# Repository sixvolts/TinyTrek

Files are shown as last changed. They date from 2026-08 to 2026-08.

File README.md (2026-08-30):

# ttos-ctf — TinyTrekOS

A small autonomous-ish car built to be hacked, and the Yocto Linux distribution
that runs it. Eight identical vehicles, each a genuine automotive network in
miniature: two CAN buses, three microcontroller nodes, a battery manager that
watches the drivetrain, and an operator panel served over the car's own WiFi that
starts out locked and opens as you solve it.

It was built for an authorized, educational capture-the-flag event. The three
challenges are the real thing rather than a simulation of one — a UDS diagnostic
server on CAN FD, an AUTOSAR-style end-to-end CRC protecting the drive bus, and
an in-kernel CAN gateway between the two — which is the point. What a team learns
breaking this car transfers to a real one.

> **Authorized use only.** Everything here targets hardware you own and a network
> with nothing else on it. Applying any of it to a vehicle you do not own, or to
> one on a public road, is neither the intent nor defensible.

> **Spoilers.** This repository is the complete build *including the answers*.
> [`WALKTHROUGH.md`](WALKTHROUGH.md) is a full solution guide, [`ARCHITECTURE.md`](ARCHITECTURE.md)
> §6 explains every mechanism, and the live flag codes appear in both. If you are
> planning to *play* one of these cars, read [`BOARD.md`](BOARD.md) and stop there.

---

## Hardware

| Part | Detail |
|---|---|
| Compute | Raspberry Pi 4, 2 GB |
| CAN | Waveshare 2-CH CAN FD HAT Rev2.1, "Mode A" (two independent SPI buses), MCP2518FD ×2 |
| Motor nodes ×2 | Adafruit QT Py SAMD21 + MCP2515, stepper drivers |
| BMS node | Adafruit Feather RP2040 CAN (built-in MCP2518FD), 12 V relay, pack-voltage sense |
| Battery | 3S pack, 8.4 V–12.3 V |

Two buses: **`can0` is DIAG** (CAN FD, 500 kbit / 1 Mbit, terminating at the
contestant's diagnostic tap) and **`can1` is DRIVE** (classic CAN 2.0, 500 kbit,
both motors plus the BMS). That naming is inverted relative to the original design
notes and it matters — see [SYSTEM-OVERVIEW.md §2](SYSTEM-OVERVIEW.md) before you
touch anything bus-related. The Pi reaches the nodes over CAN and nothing else.

## Documentation

Read in roughly this order. [`ARCHITECTURE.md`](ARCHITECTURE.md) is the source of
truth — where an older document disagrees with it, it wins.

| Document | What it covers |
|---|---|
| [ARCHITECTURE.md](ARCHITECTURE.md) | **Source of truth.** Physical layout, full CAN message map, where every secret lives, the gateway, all three challenges as built, detection and judging, panel tiers |
| [SYSTEM-OVERVIEW.md](SYSTEM-OVERVIEW.md) | The platform beneath the challenges: hardware, buses, networking, dashboard, boot and provisioning, security posture |
| [BOARD.md](BOARD.md) | Contestant-facing board copy. Safe to print or post — reveals no solutions |
| [WALKTHROUGH.md](WALKTHROUGH.md) | **Answer key.** Solving all three by hand on a real car, with the reasoning at each step |
| [THIRD-PARTY.md](THIRD-PARTY.md) | Vendored components and their licenses |
| [firmware/README.md](firmware/README.md) | The three CAN node sketches |
| [firmware/FLASHING.md](firmware/FLASHING.md) | Flashing nodes, per-car and bench modes |
| [provisioning/README.md](provisioning/README.md) | Fleet data model — how eight cars get eight identities from one image |
| [bench/README.md](bench/README.md) | The development bench rig as actually wired, and the test suite |

## Layout

```
ttos-ctf/
  meta-tt-ctf/            the Yocto layer — distro, machine, image, and every app
    recipes-apps/         ttos-dashboard (Go): panel, UDS server, CTF logic
    recipes-provision/    first-boot per-car identity
    recipes-support/      ttos-selftest, ttos-bringup, operator tooling
    recipes-core/         image definitions, systemd units, network config
    recipes-kernel/       CAN kconfig, mcp251xfd
  hardware/               build it yourself — BOM, board fab files, 3D models, schematics, build guide
  firmware/               Arduino sketches for the two motor nodes and the BMS
  bench/                  bench rig control, vehicle emulator, test suite
  tools/                  operator tooling
    ttos-ctf-tool.py      drives a car over CAN — the whole challenge chain
    linux-kit/            self-contained kit for an operator laptop
  provisioning/           fleet generation (data itself is gitignored — see below)
  kas/                    build configs
  docker/                 pinned build container
  build.sh                container build wrapper
  apps/dashboard          → symlink into meta-tt-ctf, for convenient editing
```

## Build

Needs Docker and a fast scratch directory. Upstream Yocto layers (`poky`,
`meta-openembedded`, `meta-raspberrypi`) are cloned into the repo root by `kas`
at build time and are deliberately not committed — `kas/ttos-ctf.yml` is the
source of truth for their revisions.

```bash
tmux new -s ttos                # a first build is long; sessions drop
./build.sh --build              # build the container, then the production image
./build.sh kas/ttos-ctf-dev.yml # bench/dev image instead
```

Build directories (`TMPDIR`, `SSTATE_DIR`, `DL_DIR`) live under `$TTOS_YOCTO_DIR`
(default `$HOME/yocto`), **outside** the source tree, so `rm -rf build/` does not
destroy sstate or downloads. The image lands in
`$TTOS_YOCTO_DIR/tmp-glibc/deploy/images/ttos-ctf-hw/`; flash it with
`bmaptool copy`.

## Bringing up a car

One image serves the whole fleet; per-car identity is applied on first boot from
`ttos-provision.conf` on the FAT boot partition — hostname, car id, WiFi
credentials, console password hash, challenge constants. Provisioning is
idempotent, regenerates per-car SSH host keys, then wipes the file off the FAT
partition. A missing or malformed file makes the car fail loudly on the console
rather than boot with defaults.

An **unprovisioned** card boots into factory mode: a known AP, driving enabled,
no challenge gating — which is what `tools/ttos-bringup.sh` uses to verify a
freshly assembled car before it gets an identity.

The panel is at `http://192.168.244.1` once you join the car's AP. **Use Safari
or Firefox** — Chrome's "always use secure connections" upgrades that URL to
HTTPS, which is not served, and the panel looks dead when it is fine.

## Secrets

Per-car provisioning data — WiFi PSKs, console password hashes, CRC data IDs,
challenge codes — is generated into `provisioning/` and is **gitignored**. Only
the generator scripts are tracked; `render-fleet.py` rebuilds every derived
artifact deterministically from `fleet-table.csv`. Back that file up somewhere
off this repository: losing it means reflashing every node in the fleet with new
values.

The flag codes themselves *are* in this repository, in the walkthrough and the
architecture document, because the event they were built for is over.

## License

MIT — see [LICENSE](LICENSE). Vendored third-party components keep their own
licenses, some of them LGPL; see [THIRD-PARTY.md](THIRD-PARTY.md).

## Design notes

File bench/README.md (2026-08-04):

# TTOS CTF bench rig — as built

Companion to `ttos-ctf-bench-rig.md` (the design brief) and `ARCHITECTURE.md`.
This file records what is actually wired and running on `arcana`, and **where the
brief is wrong**. Where the two disagree, this file is the one that was measured.

Built and verified 2026-08-03.

---

## Quick start

```sh
sudo ./bench-up.sh          # bring both buses up, prove the role mapping
./harness-selftest.py       # prove the harness can be trusted  <-- do not skip
./bench-status.sh           # what is the DUT actually running
./push-dashboard.sh         # rebuild + swap the Go binary, ~2 s
./push-config.sh            # sync bus config, gateway policy, selftest, units
```

---

## Topology as wired

| Role | arcana iface | Adapter | Config | Far side |
|---|---|---|---|---|
| DRIVE | `ttdrive` | Pro FD ch.1 (`dev_id 0x1`) | classic 500 k | DUT `candrive` |
| DIAG | `ttdiag` | Pro FD ch.0 (`dev_id 0x0`) | FD 500 k / 1 M | DUT `candiag` |
| DIAG (car) | `ttcardiag` | PCAN-USB FD, `0a:00.3-usb-0:3` | FD 500 k / 1 M | car 02 diagnostic port |

**The vehicle is normally NOT attached.** Car 02 sat on `ttcardiag` during
development; it goes to the event. The DUT stays, so the bench remains useful
remotely — but it is worth being exact about what that does and does not cover.

| Runs against the DUT (emulated nodes) | Needs a real vehicle |
|---|---|
| `harness-selftest`, `test-uds`, `test-gateway` | `soak.py` — C5 and D11 |
| `test-detectors`, `test-challenge`, `test-c3` | anything about real firmware timing |
| `test-panel` (incl. `--reboot`), `test-relay` | physical motion, real drivetrain |
| `bench-status`, `push-*`, `measure-drive` | the 12 V rail actually switching |

The DUT proves the **protocol and the logic**. It cannot prove the **firmware**:
`vehicle-emulator.py` is a Python model of the BMS and motor nodes, and a passing
detector test says the rules are right, not that the RP2040 implements them. That
distinction has already mattered twice — the C2 pair-window bug and the dead 12 V
rail were both found on a real car, and the second was actively masked on the bench
because `emu-ctl rail on` forces the rail that no product path was setting.

`soak.py` refuses to run without a vehicle rather than failing deeper with a socket
error, and says which of the two things is missing.

**The DUT rig is one dual-channel PCAN-USB Pro FD** since 2026-08-04, replacing two
single-channel dongles. That change broke the old port-based pinning outright:
**both channels share one `ID_PATH`**, because they are one USB interface. A rule
keyed on the port matched whichever channel probed first and left the other as
`can1` — the same probe-order race this project already fought on the Pi.
`peak_usb/can_channel_id` is no help either; it reads `80FF0000` on both. The
discriminator is `ATTR{dev_id}`, the channel index.

The DUT names its own interfaces by role too, from `10-ttos-can.rules` in the
image — `candrive` is the HAT's CAN0 terminal (`spi0.0`), `candiag` is CAN1
(`spi1.0`). Both sides therefore read as roles end to end, and neither depends on
kernel probe order.

DUT: `192.168.4.133`, user `ttos`, unprovisioned (factory mode, password `ttos`).
Key auth is installed from `arcana`, so scripts run without a password prompt;
`sudo` on the DUT is fed the factory password on stdin rather than being given a
NOPASSWD drop-in, so the DUT keeps stock privilege config.

Adapters are two **PEAK PCAN-USB FD** — both FD-capable, so the brief's "this
leaves both table loaners free" holds.

---

## Corrections to the brief

### 1. `CAN_RAW_LOOPBACK` on the observer does nothing (§3)

The brief calls this the cleaner of its two fixes for the loopback trap. It does
not work. Measured here:

```
LOOPBACK=0 on the RECEIVER  -> receiver still saw the injected frame
LOOPBACK=0 on the SENDER    -> receiver did not
```

The option governs whether frames **that socket transmits** are echoed to other
local sockets. On a receive-only socket it suppresses the echo of frames it never
sends, i.e. nothing.

Worse, an observer built to the brief still **passes the brief's own self-test**,
because that test only asks whether the injected frame was absent — and a socket
that receives nothing at all answers yes. So the prescribed check certifies the
broken implementation.

`ttoscan.Observer` filters on the receive side instead: the kernel sets
`MSG_DONTROUTE` in `recvmsg` `msg_flags` for any frame that came from a local
socket, and leaves it clear for frames off the wire (measured: `0x4` for injected,
`0x0` for the DUT's heartbeat). This beats both of the brief's options — sender-side
suppression only covers injectors that opt in, so `cansend`, ad-hoc scripts and the
panel all still leak; frame bookkeeping needs every transmitter to report to a
ledger. `MSG_DONTROUTE` is the kernel's own statement of provenance and needs
cooperation from nobody.

`harness-selftest.py` therefore adds **positive controls** (T1, T3) around the
negative check (T2). T2 alone is unfalsifiable.

### 2. Adapters are pinned to role names, not numbers (§1)

A script that says "observe `ttdiag`" cannot be silently backwards, whatever the
cabling is. That paid for itself on 2026-08-03, when the bus roles turned out to be
the reverse of what the config claimed — DRIVE is the car's `can0`, not `can1` —
and correcting the whole rig took two lines and no cable moved.

**And then it bit, because the same commit edited these two lines as well.** The
car-side correction was right; the bench mapping was already right and got
inverted along with it. For a day, every bench observation was on the wrong wire:
the DUT looked silent on DRIVE while transmitting normally. Nothing failed loudly,
because a swapped pair makes negative assertions pass.

The rule that falls out of that: **which arcana USB port is cabled to which DUT
bus is a physical fact, and a role correction at the far end is never also a
correction here.** Verify this file against traffic, not against reasoning about
the other end — which is exactly what `bench-up.sh` does, and it catches this
inversion in 1.5 s. It simply had not been run in between.

### 3. Pin by USB port, not adapter serial (§2)

PCAN-USB FD publishes no USB `iSerial`; there is no serial to match on. The rules
key on `ID_PATH` (physical port). **The role follows the port, not the adapter** —
move a cable and the roles move with it. `bench-up.sh` re-verifies the mapping
against the DUT's 0x100 heartbeat on every run, so a mis-plug aborts instead of
inverting every result.

### 4. `cmd/ctfd` / `ttos-ctfd` do not exist (§5)

There is no separate CTF daemon. The challenge layer lives inside the dashboard:
`cmd/dashboard/ctf.go` and `cmd/dashboard/uds.go`. Building `./cmd/ctfd` fails
loudly (fine); restarting a nonexistent `ttos-ctfd` succeeds *quietly* and leaves
the old code running (not fine). `push-dashboard.sh` targets `ttos-dashboard`.

### 5. `install(1)` is not on the DUT

busybox is built without it. `push-dashboard.sh` uses `cp` + `chmod` + `mv`, which
keeps the atomic-rename property that matters (the running process holds its old
inode; a half-copied binary can never be exec'd).

---

## Deliberate choice: the DRIVE adapter is CLASSIC

The real drive-bus nodes are MCP2515s with no FD support at all. Configuring
`ttdrive` classic makes it fail the way they do — a genuine FD frame becomes a form
error rather than data. That turns the adapter into a **canary** for the FD hazard
(matrix G3) instead of an FD-tolerant observer that would quietly absorb the exact
frame we are trying to prove never arrives.

`bench-up.sh` passes `fd off` explicitly and then re-reads the kernel's view to
confirm. This is not belt-and-braces: setting `bitrate` alone leaves whatever FD
state the interface last had, so an adapter previously used as DIAG comes back up
FD-capable while the script cheerfully reports `CLASSIC`. That happened here on the
first run, and the only outward sign was a `dbitrate` line in `bench-status.sh`.

Set `DRIVE_FD=1` only to *capture a stray FD frame's contents*, never to run G3.

---

## Updating the DUT without a card swap

```sh
./push-dashboard.sh          Go binary          ~2 s
./push-config.sh             platform files     ~10 s  (--dry-run to preview)
```

`push-config.sh` syncs the files a Go rebuild cannot touch — `candrive/candiag.network`,
the udev naming rule, the AP network file, the `cangw` policy and its unit,
`ttos-selftest`, `ttos-provision`, `ttos-dashboard.default` and its unit — straight
from the source tree, then reconfigures the interfaces they describe. It compares
by sha256 and pushes only what differs.

**CAN link parameters can only be set while the interface is DOWN**, and
`systemd-networkd` will not bounce a link just because its `.network` changed. So
`networkctl reload` alone leaves an FD interface FD forever and the push looks like
it did nothing. The script takes both links down first — and then verifies against
the kernel anyway, because `networkctl reconfigure` was measured here NOT to clear
FD state it did not set (the same trap as `bench-up.sh` on the host side). It falls
back to an explicit `ip link set candrive up type can bitrate 500000 fd off`.

Interestingly, a **reboot** applies the file cleanly — the interface comes up
classic from the driver default and networkd only ever adds `BitRate`. So the
forced fallback matters for live iteration, not for a freshly booted car.

Still needs a real flash: kernel, device-tree overlays, layer/recipe changes,
package sets, and anything on the FAT boot partition. And this makes the *files in
the manifest* match — not the whole image. **Flash the real `.wic` and re-run the
suite before any milestone or go/no-go**; treat config push as the iteration path,
not the sign-off.

## Test matrix status

| Group | Covered | Result |
|---|---|---|
| Gateway | **G1–G6 complete** | 5/5 |
| Diagnostic | **D1–D10 complete**; D11 needs a soak | 11/11 + 8/8 |
| Challenge | **C1–C4, C6–C8**; C5 needs the 30-minute soak | 8/8 + 6/6 |
| Panel | **P1–P8 complete** | 13/13 |
| Relay | R1–R9 (not in the brief; C3 needed them) | 9/9 |

```sh
./provision-bench.sh 01                 # stage car 01's identity (identity only)
./vehicle-emulator.py --car 01 &
./harness-selftest.py   4/4    harness isolation
./test-gateway.py       5/5    G1-G5 (re-run after a reboot = G6)
./test-detectors.py     8/8    C2/C3 rules
./test-uds.py --car 01  11/11  diagnostic server + the C1 pivot routine
```

`provision-bench.sh` stages `/etc/ttos/provision.src` only — it deliberately does
NOT run `ttos-provision`, which would also set the hostname, switch the AP to WPA2,
reset the drive interface to read-only and replace the `ttos` password with the
fleet hash, breaking the factory password every bench script feeds to `sudo -S`.
The DUT therefore still reports itself unprovisioned and self-test sections 1 and
10 still fail; that is expected. **It also means the provisioning path itself is
not under test here** — flash a real image and run `ttos-provision` properly before
the fleet is built.

G3 is only meaningful because the DRIVE adapter is classic **and** the DUT's
`candrive` is classic. Both halves matter: an FD-tolerant observer absorbs the frame, and an
FD-capable DUT can still emit one.

Watch for two traps when adding cases, both of which bit here on first run:
the drive bus legitimately carries the DUT's `0x100` heartbeat, so a bare
`collect()` counts normal traffic as a leak; and a negative assertion over a dead
bus passes for free, so pair it with a liveness check (`bus_is_live`).

## Previously-known drift, now closed

The DUT was one image behind (pre-`112e243`): the drive bus still `FDMode=yes`, so it could
transmit CAN FD onto the drive bus and **G3 could not be closed on it**. Fixed with
`push-config.sh` on 2026-08-03, verified by `bench-status.sh`, the DUT self-test
(`candrive is classic CAN 2.0`), and G3 passing. The gateway also survives three
consecutive self-test runs at 2 rules, which is the proof the old destructive
`cangw -F` is gone.

## First provisioned-car run (2026-08-03)

Image `…rootfs-20260803163625.wic` flashed, `ttos-provision.conf` (car 01) consumed
on first boot. `ttos-selftest`: **40 PASS / 0 FAIL / 3 SKIP** — sections 1 and 10
pass for the first time, and `push-config.sh` found *only* `ttos-provision`
differing from source, so the image matched the tree everywhere else.

Full suite against the provisioned car: harness 4/4, gateway 5/5, detectors 8/8,
UDS 11/11, challenge 8/8.

Two bugs that only a real provisioning run could surface:

**`install(1)` in `ttos-provision.sh`.** There is no `install` on this rootfs —
busybox is built without it. `install -d -m 700 /home/ttos/.ssh` failed, so the
directory was never created, the `authorized_keys` redirect failed too, and the key
was silently not deployed. Nothing else depends on it, so provisioning reported
success; the only symptom is that key auth does not work, found whenever someone
next logs in without a password. Now `mkdir -p` + `chmod`, both with `|| fail`.

This one is doubly annoying: the same fact is already written down as correction 5
above, from fixing `push-dashboard.sh` — the fact was known and never applied to
the rest of the tree. A `grep -rE 'install +-'` across everything that runs *on the
car* takes seconds and was not done. It is done now, and `timeout`/`getent` were
swept at the same time (the only other hits are comments).

**The self-test still asserted `provision.src` mode 600.** The DynamicUser fix
changed it to `640 root:ttos-secrets` and the guard was not updated with it, so the
first provisioned boot reported a failure for doing the right thing. The check now
verifies mode *and owner*: `640 root:root` is just as broken as `600` and looks
correct at a glance.

## Vehicle emulator

```sh
./vehicle-emulator.py --car 01     # two motor nodes + BMS on the DRIVE bus
./emu-ctl.sh status                # state + counters
./test-detectors.py                # 7 C2/C3 rule cases
```

Provisioned as **car 01** — Data IDs `L=0x60B0` / `R=0x045C`, codes `C2=2FQYWXDM`,
`C3=3CX5E77Z`. Per brief §7 the bench must stay one car: a mismatch presents as
universal silent CRC rejection, which is indistinguishable from a bus fault.
(`fleet-table.csv` is gitignored, so the emulator needs `provisioning/` present.)

Verified against the live DUT:

- Beacon reaches the dashboard end to end — `emu-ctl.sh vbat 9500` moved the SSE
  battery reading 100% → 53%, matching the computed 53.8%.
- Heartbeat arm mask decoded as `0x03` (both detectors armed on a locked car).
- Driving the DUT via `/api/control` fired `0x7D1` and `0x7D2` carrying car 01's
  real codes, **and both reached the DIAG bus through the DUT's `cangw` policy —
  matrix G5 passes.** That is the rule whose omission ships an unsolvable event.
- CRC: valid frame accepted, 5 corrupted frames and 1 frame keyed to car 02's Data
  ID all rejected with **zero** response frames (silent rejection; matrix C8).
- LVC latches after the 1.5 s debounce and clears above 9000 mV, rail staying off
  until an explicit `0x115`, matching `TinytrekBMS.ino`.

`crc8_j1850` checks out against the standard vector (`"123456789"` → `0x4B`), and
the equivalence-class result reproduces independently: 1, 2 and 3 captures all
leave exactly 256 candidate Data IDs.

### Findings from building it

**1. The brief's heartbeat requirement is wrong, and the real behaviour is worse.**
§4 says the emulator must "refuse motion when absent, matching real node behaviour."
`TinytrekLMotor.ino` does no such thing — `heartbeatOK()` and `powerOK()` feed
`updateLed()` and nothing else; the step-drain block is gated on `stepsLeft > 0`
alone. A motor node with no heartbeat and no beacon still pulses STEP. What stops
the car is electrical: the BMS holds the 12 V rail off. The emulator models the
firmware (buffer drains unconditionally) and tracks the rail separately, so a test
can tell "commanded but unpowered" from "not commanded". **Do not design a
challenge around "no heartbeat = no motion"** — it is false on the vehicle.

**2. C3 must key on same-`dir`, not on `rpm` alone.** The layering doc says
"detection keys on `rpm`" and "`rpm` already distinguishes the two cases", which
invites exactly the rule I first wrote. It passed the positive test and would have
failed in the only case that matters — see finding 3. The `dir` condition is what
actually discriminates; `rpm` is a filter on top of it.

**3. The resonance fix has undermined the spec's `rpm` discriminator.** The spec
rests on: pivot = `rpm` 50 (legitimate), straight = `rpm` 100 (never legitimate
while locked). But turn speed was raised to 100 on 2026-08-02 because 50 rpm sits
in the steppers' mid-band resonance and grinds. So the C1 pivot routine at `rpm`=50
**will grind audibly at every station**, and raising it to 100 makes `rpm` stop
discriminating. Detection survives either way *because* of the same-`dir` condition
(`test-detectors.py` case 2 proves a 100 rpm pivot stays silent), but the spec text
is now misleading and anyone porting it who simplifies to `rpm == 100 → C3` will
leak the C3 code on the car's own pivot. **Open decision before Phase 2: what rpm
does the pivot run at, and does the 102-step arc still hold there?**

**4. Two spec numbers are missing and are currently bench-tuned.** The C2 pair
window ("within a short window") is set to 250 ms — the dashboard keepalive is
150 ms, so both wheels are commanded inside one cycle. And "15 consecutive
qualifying commands" is ambiguous between CAN frames and command cycles (each cycle
sends two frames); this counts frames. Both need a decision before the RP2040 port.

**5. Emulated nodes must NOT use the wire-only filter** — the inverse of test
observers. A real node is a separate device, so everything reaching it is wire
traffic by definition; an emulator on the harness host that filters `MSG_DONTROUTE`
is deaf to exactly the frames the tests inject. On first run all four positive
detection cases failed while all three negative cases "passed", which is the worst
possible arrangement. Rule: **emulated nodes hear everything, test observers hear
only the wire.**

Consequence for the test runner: a DRIVE-side `Observer` cannot see the emulator's
own transmissions. "Did the emulated BMS emit a flag?" is answered by its counters;
"did the flag cross the gateway?" is answered by a DIAG `Observer`.

### The bug this phase caught

`ttos-dashboard.service` runs `DynamicUser=yes` — a transient unprivileged user —
while `ttos-provision.sh` staged `/etc/ttos/provision.src` as **600 root:root**. The
dashboard therefore could not read its own challenge identity on a provisioned car:
no VIN, no ECU serial, no unlock codes, every challenge dead.

It survived this long because it is invisible until the two halves meet. Every
hardware run so far was in factory mode, where the file legitimately does not exist
and the log line is the *same* "provision.src unreadable" error. A provisioned car
would have looked healthy — dashboard up, buses up, gateway live — and simply had
no challenges.

Fixed by staging the file `640 root:ttos-secrets`, adding that group to the image,
and giving the unit `SupplementaryGroups=ttos-secrets`. Verified on the DUT:
`CTF identity loaded for car 01`. The file stays unreadable to the panel and to
any contestant with a shell.

### Findings from Phases 4 and 5

**`crypto.subtle` is unavailable on the car's own panel.** SubtleCrypto exists only
in a secure context; the panel is plain HTTP on the AP address, so
`window.crypto.subtle` is `undefined` there. The C3 key transform ships in the
panel JS by design — contestants view source and run it — so building it on
SubtleCrypto would have thrown on the one platform it exists for, killing the
intended solution while nothing looked broken. It ships a bundled SHA-256, verified
in headless Chromium against a reference implementation over a genuinely non-secure
origin (`isSecureContext=false`, `crypto.subtle=undefined`), including the
multi-block padding path.

**ENOBUFS on the relay under sustained load.** The drive bus is 500 kbit and the
interface transmit queue is ten deep, so a client writing as fast as TCP allows
overran it: 80 frames issued in ~0 ms, 29 rejected. A contestant would have seen
the car stutter and concluded their forgery was wrong, then gone back to
re-deriving a CRC that was already correct — the exact unfair stalling the design
sets out to avoid. Bounded retry now paces the sender to bus speed.

Found only by driving the car through the relay. No unit test of `relaySend` would
have produced it.

**busybox `nc` silently loses commands.** It exits on stdin EOF, and closing a
socket with unread received data sends RST, discarding whatever the server had not
processed — 19 of 40 SEND commands. Not a relay bug, but contestants will reach for
`nc` first, so the banner tells them to read every response, and it ends with a
`READY` sentinel so clients need not count banner lines (adding a line silently
broke every client, which is how that was found).

**`Storage=persistent` was applied and did nothing.** `/var/log` is a symlink into
the `/var/volatile` tmpfs, so the "persistent" journal was still wiped on reboot.
systemd accepted the drop-in and `/var/log/journal` never appeared. It matters here
because there is no RTC and journald is the only record of a solve, and the
power-cycle that hands a station to the next team is exactly when it would vanish.
Fixed with `VOLATILE_LOG_DIR = "no"`; needs an image build, not a config push.

**A self-test check that Phase 5 made wrong in both directions.** It asserted
`TTOS_DASH_FRAMES` was empty, which was equivalent to checking behaviour until
per-session tier gating became the real control. After Phase 5 it fails a correctly
configured car, and an empty variable with broken tier logic would pass. It now
queries what an unauthenticated client actually receives from `/api/info`. General
lesson: assert the behaviour, not the setting that used to imply it.

### Fault injection

`drop <pct>`, `mute on|off`, `latency <ms>`, `lvc on|off`, `vbat <mv>`,
`sweep <lo> <hi> <secs>`, `rail on|off`, `reset`.

`mute` stops transmission but the controller still ACKs, so it is not bus-off.
Nothing in userspace can withhold an ACK — for a genuinely absent node (the ENOBUFS
case that has bitten this project repeatedly) take the interface down instead:
`sudo ip link set ttdrive down`.

## Not yet built

- **Test matrix runner** — brief §6. Covered so far: G5, C7, C8, partial C5.
  Outstanding: G1–G4, G6, all of D, C1–C4, C6, all of P.
- **Remote power control** — no `uhubctl`, no switchable hub. A wedged DUT still
  needs a human, which caps unattended iteration.
- **Serial console** — nothing on `/dev/serial/by-id`. When networking is what
  broke, there is currently no way in.
- **`rpiboot` reflash path** — not installed; flashing still means moving the card.
- ~~Static DUT address~~ — **done, better than the brief asks.** `192.168.4.133` is a
  static DHCP *reservation on the router*, keyed by MAC. Do NOT "fix" this by
  setting `TTOS_ETH_ADDRESS` in provisioning (bench brief §7): a DUT-side static
  address would fight the reservation, and it would have to be re-applied on every
  reflash, whereas the reservation survives them and follows the hardware.

## What the rig still cannot tell you

Unchanged from brief §8, and worth re-reading before trusting a green suite: node
firmware correctness, stepper/drivetrain behaviour (including the known left-motor
stutter), real bus timing, RF, physical containment. The emulator will test the
*specification*; one real car still has to close the loop before the fleet is
flashed.

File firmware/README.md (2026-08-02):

# TinyTrek node firmware

The CAN nodes on the car's drive bus (classic CAN 2.0 @ 500 kbit). **On the current
hardware this bus enumerates on the Pi as `can1`, not `can0`** — verified 2026-08-01
(motors + BMS answer there; `can0` has no nodes and writes fail with `ENOBUFS`).

Boards: motor nodes are **Adafruit QT Py SAMD21 + MCP2515** (`CAN.setPins(3, 0)`);
the BMS is an **Adafruit Feather RP2040 CAN** (built-in MCP2518FD).

| Sketch | CAN ID | Role |
|---|---|---|
| `TinytrekLMotor` | `0x111` | left stepper (consumed step buffer): `[steps:uint32 BE][dir][rpm]` — ADDS `steps` to a capped buffer the node drains as it steps; dir `0x02`=reverse / `0x01`=forward / `0x00`=stop (clear); `rpm` sets speed. |
| `TinytrekRMotor` | `0x113` | right stepper: same format |
| `TinytrekBMS` | `0x115` | RX power command: `[0x01]`=12V on, `[0x02]`=off |
| `TinytrekBMS` | `0x116` | TX **beacon** @5 Hz: `[v_hi][v_lo][pwr][flags]` — pack mV (uint16 BE), `pwr` `0x01`=rail on / `0x02`=off (the **actual** state, not the commanded one), `flags` bit0 = low-voltage cutoff latched |
| *(the Pi)* | `0x100` | TX **heartbeat** @5 Hz: `[seq][flags]` — "the Pi is alive and in control". `flags` bit0 = C2 detector ARMED, bit1 = C3 detector ARMED (see below) |

The dashboard's control pad drives these verbatim (see `meta-tt-ctf/recipes-apps/ttos-dashboard`).

## Status LEDs — reading the system state off the robot

Every node's onboard NeoPixel reports the health of the **whole chain**, so a
glance tells you which link is broken. Both periodic messages (`0x100`, `0x116`)
run at 5 Hz with a 1 s timeout on the motor nodes.

**Motor nodes** — two things must be true to leave red: a Pi heartbeat *and* a BMS
beacon saying the 12 V rail is on.

| LED | Meaning |
|---|---|
| 🔵 **solid blue** | **CAN controller never initialised** — board/SPI fault, retrying |
| 🔵 **blink blue** | controller up, but **not one frame ever received** — bus/wiring |
| 🟢 solid green | **READY** — heartbeat + 12 V both good, not moving |
| 🟡 solid yellow | **ACTIVE** — propulsion commanded and running |
| 🔴 **double**-blink red | no heartbeat from the Pi (12 V is fine) |
| 🔴 **regular** blink red | no 12 V active (heartbeat is fine) |
| 🔴 solid red | both missing |

So: *blue means this node can't talk at all; red means it can hear the bus but the
system isn't ready; blink pattern says which signal is missing.*

**Blue is a board fault, red is a system fault.** Solid blue will not be fixed by
any amount of cable work — the MCP2515 isn't answering over SPI. Blinking blue is
the opposite: the controller is fine and nothing is reaching it, so check wiring,
termination and bit rate. A healthy bus always carries the BMS beacon at 5 Hz, so
"never received a frame" is always a real fault.

### Why the blue states exist

They were added on 2026-08-02 after a car burned an afternoon. `CAN.begin()` failed
at power-on, the sketch printed to a serial port nobody was attached to and **carried
on anyway**, and the node sat in configuration mode forever. In that state the
controller is electrically passive: it neither acknowledges frames nor corrupts the
bus. From the Pi everything looked healthy — another node was providing the ACK, so
transmits succeeded and the error counters stayed at zero — while the motor node
heard nothing. On the robot it showed as solid red, identical to a disconnected bus.

Two fixes came out of it, both in the sketch rather than the vendored library:

- **Settle, then retry.** The MCP2515 needs its oscillator running before it answers
  over SPI (128 osc cycles plus crystal settling, up to milliseconds from cold), but
  the library's `reset()` waits only 10 µs. So `begin()` can lose that race at cold
  power-on and win it on a warm reset. The sketch now waits 50 ms before its first
  attempt and **retries every second until it succeeds**, non-blocking.
- **SPI at 4 MHz** instead of the library's 10 MHz default, which is the MCP2515's
  absolute maximum and marginal over hand-wired jumpers.

`begin()` does verify SPI communication (it reads `CANCTRL` back twice), so a
success genuinely means the controller is there. It does **not** verify the crystal:
bit timing is chosen from whatever `CAN_CLOCK_HZ` claims. An 8 MHz module told 16 MHz
reports success and then runs at half rate — deaf, and it corrupts the bus with error
frames. That last part is diagnostic: a wrong-crystal node *dirties* the bus, so if
the Pi's error counters are clean the problem is not bit rate.

For 8 MHz modules, build with:

```bash
./build.sh <fqbn> TinytrekLMotor --build-property "build.extra_flags=-DCAN_CLOCK_HZ=8000000"
```

### Serial status

Each node prints its state every 2 s — `CAN=up rx=yes hb=ok 12v=on steps=0`, or the
reason it is down. Deliberately periodic, not once at boot: these are native-USB
boards, so **a reset drops the CDC connection** and anything printed during `setup()`
is gone before a monitor can reattach. That is precisely why the original one-shot
"Failed to initialize CAN BUS." message was never seen by anyone.

The heartbeat is transmitted **unconditionally** by the CTF service layer. It used
to ride the dashboard's drive gate, so a read-only car transmitted nothing and its
motor nodes double-blinked red by design — that is no longer true, and a CTF car
must keep the heartbeat alive while its panel is locked or no challenge can move
the wheels. A car showing double-blink red now means the Pi really is not talking.

### Heartbeat `flags` byte — detector arm mask

`0x100` byte 1 tells the **BMS** which of its detectors should be armed:

| Bit | Meaning when SET |
|---|---|
| 0 (`0x01`) | C2 detector armed (watch for same-`dir` on `0x111`/`0x113`) |
| 1 (`0x02`) | C3 detector armed (watch for sustained forged commanding) |

A locked car sends `0x03`; each bit clears when that challenge's code is redeemed
on this car, so an unlocked panel driving normally does not re-trigger detection.

**Positive arming, deliberately.** With "redeemed" semantics `flags == 0` would
mean *armed*, so a Pi bug, a short frame, or mismatched firmware would leave
detection live and the car would leak its C2 code during ordinary driving. With arm
semantics those same failures leave detection **disarmed** — the challenge does not
fire, someone reports a broken station, and it gets fixed. A dead station is
recoverable; a leaked flag is not. So the BMS must treat a stale heartbeat (>1 s,
the same timeout the motor nodes use) or a DLC < 2 as **arm mask 0**.

The Pi re-reads the mask every tick, so the BMS *mirrors* current state rather than
latching an event: a dropped frame self-corrects in 200 ms, a node that power-cycles
re-syncs with no re-announcement, and restarting the service re-arms both detectors.

## Building (vendored libraries — no global install)

Dependencies are **vendored** under `libraries/`, so builds don't depend on
whatever is installed globally:

- `libraries/CAN/` — Sandeep Mistry `arduino-CAN` (MIT), the `CAN.h` API.
- `libraries/Adafruit_NeoPixel/` — Adafruit NeoPixel (LGPL-3.0), the status LEDs
  (all three nodes). QT Py SAMD21 uses `PIN_NEOPIXEL` = 11 and has no
  `NEOPIXEL_POWER` gate pin; the Feather RP2040 CAN has both. The sketches guard
  on `#ifdef`, so the same code is correct on either board.

**With `arduino-cli`:**
```bash
./build.sh arduino:avr:uno                    # all three
./build.sh arduino:avr:uno TinytrekBMS /dev/cu.usbmodemXXXX   # build + upload one
```
The script passes `--libraries ./libraries` so the compiler uses the vendored copy.

**With the Arduino IDE:** point it at the vendored library once, then open the
sketches normally:
```bash
ln -s "$(pwd)/libraries/CAN" ~/Documents/Arduino/libraries/CAN
```

## Notes / tunables

- **FQBN**: set to your actual node board. The nodes are **RP2040** (3.3 V) with a
  built-in MCP2515 — the sketch's `PIN_CAN_CS`/`PIN_CAN_INTERRUPT` come from the
  Adafruit Feather RP2040 CAN variant (`rp2040:rp2040:adafruit_feather_can` in the
  earlephilhower core). (The "Arduino UNO" header comment is a stale leftover.)
- **Consumed step buffer (smooth + loss-tolerant) + speed byte**: each command
  ADDS its `steps` to a capped buffer (`STEPS_MAX`, 250 — ~2.5× the dashboard's
  per-frame chunk) that the node drains as it steps, staying energised while the
  buffer holds steps. Motion follows the buffer, not message timing, so dropped or
  jittered frames don't stall it — it keeps stepping off the reservoir. `rpm` sets
  speed; the dashboard adds `TTOS_DASH_STEP_CHUNK` (100) steps every ~150 ms
  keepalive — about 2× what's consumed between frames, so the buffer fills to the
  cap and rides a couple of missed frames — and a release/stop sends `dir 0x00`
  to clear it promptly. The cap bounds coast and
  makes runaway impossible (it halts within `STEPS_MAX` steps if commands stop).
  Bigger `STEPS_MAX` = smoother through heavier loss but longer coast if a release
  is missed. `int rpm = 100;` is only the fallback speed when a frame omits the
  `rpm` byte.
- **`TinytrekBMS`** uses `CAN.setPins(PIN_CAN_CS, PIN_CAN_INTERRUPT)` — those macros
  are board-specific; set literal CS/INT pins (like the motor sketches' `setPins(3, 0)`)
  to match your MCP2515 wiring if they aren't defined for your board.
- **Battery sense**: a 120 kΩ / 40.2 kΩ (0.5%) divider on the 12 V pack feeds BMS
  `A1` (ratio 0.2509; `Vbat = Vadc × 3.985`). `TinytrekBMS` reads it and transmits
  `Vbat` (mV, uint16 BE) on `0x116` at ~1 Hz. `ADC_REF_MV = 3300` (3.3 V board); if
  the gauge is slightly off vs a multimeter, nudge that constant.

## BMS status LED (onboard NeoPixel)

`TinytrekBMS` drives the Feather RP2040 CAN's onboard NeoPixel as a state light.
**Blink rate = 12 V relay; color = battery band; fast blink is reserved for the
low-voltage cutoff.** Bands come from the same 3S range as the dashboard gauge
(8.4 V = 0 %, 12.3 V = 100 % → 50 % = 10.35 V, 25 % = 9.375 V; cutoff 8.5 V):

| Battery band | 12 V **off** (solid) | 12 V **on** (slow blink) |
|---|---|---|
| ≥ 50 % | 🟢 solid green | 🟢 slow-blink green |
| 25–50 % | 🟠 solid amber | 🟠 slow-blink amber |
| < 25 % (above cutoff) | 🔴 solid red | 🔴 slow-blink red |
| below cutoff (8.5 V) | 🔴 **fast-blink red** (12 V forced off) | — |

Timing/brightness knobs: `BLINK_SLOW_MS` / `BLINK_FAST_MS` / `LED_BRIGHTNESS`.
The pixel is on `PIN_NEOPIXEL` (from the board variant); `NEOPIXEL_POWER` is
enabled if the variant defines it. Update is non-blocking (throttled millis
blink, `show()` only on change) so it never stalls CAN RX or the cutoff loop.

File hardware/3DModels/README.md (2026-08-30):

# 3D models:

You will need a 3D printer with at least an 8inx8in (203mmx203mm) print area to print the chassis.

# Required models:
There are 3 Required models: TinyTrekV1pt5.stl, battExtender.stl, in this repo and m12_flashlight_lower_body at the following link: https://www.printables.com/model/96306-milwaukee-m12-flashlight-with-adjustable-head

# Optional models:
Cam Bracket.stl and snapConnectorBracket.stl are for optional additions to the project.

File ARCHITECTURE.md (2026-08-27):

# TTOS CTF — architecture and challenges, as built

**This document is the source of truth for the CTF design.** It describes the system
as built and as intended; where an older design note disagrees with it, this file
wins. Written from the code rather than from the design docs, and kept current as
the implementation changes.

---

## 1. Physical layout

One Raspberry Pi 4 and three microcontroller nodes per car, on two CAN buses.

```
                    ┌──────────────────────────────────────┐
                    │  Raspberry Pi 4  (ttos-dashboard)    │
                    │  panel · UDS server · gateway · relay│
                    └───┬──────────────────────────┬───────┘
            candrive    │                          │  candiag
          DRIVE bus     │                          │   DIAG bus
     classic 500 kbit   │                          │   CAN FD 500k/1M
                        │                          │
        ┌───────┬───────┴───────┐                  │
        │       │               │                  │
   ┌────┴───┐ ┌─┴──────┐ ┌──────┴──┐        ┌──────┴─────────┐
   │ L motor│ │ R motor│ │   BMS   │        │ contestant tap │
   │ SAMD21 │ │ SAMD21 │ │ RP2040  │        │  (FD adapter)  │
   │+MCP2515│ │+MCP2515│ │+MCP2518 │        └────────────────┘
   └────────┘ └────────┘ └─────────┘
```

**The interfaces are named for their role: `candrive` and `candiag`**, pinned to
SPI address by `/etc/udev/rules.d/10-ttos-can.rules`. `spi0.0` is the HAT's CAN0
terminal (the motor and BMS harness); `spi1.0` is the CAN1 terminal (the contestant
diagnostic port). The device-tree overlay fixes that mapping, so it is identical on
every car.

**They are not called `can0`/`can1` for a reason that cost days.** Left to the
kernel, the two MCP2518FD controllers are named in whatever order they probe, and
that order RACES — the same car, physically unchanged, came up with the drive
harness on `can0` one boot and `can1` the next. Every symptom of that looks like a
wiring fault, and it produced a bus-role claim recorded as "verified on hardware"
that was simply a snapshot of one boot's dice roll.

Two things had to be fixed. The `.link` files that were supposed to pin the names
could never have worked: they match on `Path=`, which compares udev's `ID_PATH`, and
`ID_PATH` is empty for SPI-attached CAN controllers — `networkctl` said
`Link File: n/a` on every car. And renaming to `can0`/`can1` cannot work either,
because udev will not swap two interfaces into each other's names; the rename fails
silently and leaves the racy order. Role names avoid the collision entirely, and a
config that says `candrive` cannot be quietly pointing at the diagnostic bus.

| | DRIVE (`candrive`) | DIAG (`candiag`) |
|---|---|---|
| Speed | classic CAN 2.0, 500 kbit | **CAN FD**, 500 kbit arb / 1 Mbit data |
| Who is on it | 2 motors, BMS, Pi | Pi, and a contestant's adapter |
| Idle traffic | heartbeat + beacon, ~23 frames/s | **silent** until a request arrives |

`candrive` is classic because the motor nodes are MCP2515, which has no FD support at
all — an FD frame there is a form error that drives them error-passive and then
bus-off, stopping propulsion. FD is disabled in configuration so the Pi cannot emit
one even by mistake.

`candiag` is FD because responses do not fit otherwise: VIN 20 bytes, pivot response
12, snapshot 23. **A classic-only adapter can transmit every request and will never
receive an answer.**

---

## 2. CAN message map

| ID | Direction | Bus | Payload |
|---|---|---|---|
| `0x100` | Pi → nodes, 5 Hz | DRIVE | `[seq][armMask]` — liveness + detector arming |
| `0x111` | Pi → left motor | DRIVE | drive command |
| `0x113` | Pi → right motor | DRIVE | drive command |
| `0x115` | Pi → BMS | DRIVE | `[0x01]` 12 V on / `[0x02]` off |
| `0x116` | BMS → all, 5 Hz | DRIVE | `[v_hi][v_lo][pwr][flags]` pack mV, rail state, LVC |
| `0x7D1` | BMS → bus, 2 Hz while triggered | DRIVE→DIAG | C2 code, 8 ASCII |
| `0x7D2` | BMS → bus, 2 Hz while triggered | DRIVE→DIAG | C3 code, 8 ASCII |
| `0x7D5` | Pi → bus, echoing `0x7D1` | DIAG | `FLAG{<C2 code>}`, 14 ASCII, **FD** |
| `0x7D6` | Pi → bus, echoing `0x7D2` | DIAG | `FLAG{<C3 code>}`, 14 ASCII, **FD** |
| `0x7DF` / `0x7E0` | tester → Pi | DIAG | UDS functional / physical request |
| `0x7E8` | Pi → tester | DIAG | UDS response |

### Why the flags appear twice

A flag has to be recognisable as a flag in a raw capture. A contestant in SavvyCAN
or `candump` who sees eight printable characters go past on an otherwise binary bus
has no way to know that was the prize unless someone already told them — which makes
*solving* the challenge and *knowing you solved it* two different skills, and only
one of them is under test.

`FLAG{XXXXXXXX}` is fourteen bytes. The C2 and C3 codes are emitted by the BMS on
the DRIVE bus, which is classic CAN with an eight-byte payload and classic-only
MCP2515 nodes; the wrapper cannot go there, and shortening the code to fit would
mean a firmware change plus a `flash_nuke` erase of every BMS in the fleet, because
the codes are write-once.

So the wrapper is applied where the code is *presented* rather than where it is
emitted. C1 already arrives on the FD diagnostic bus and is wrapped at source, in
the routine response. C2 and C3 are re-announced by the dashboard on `0x7D5`/`0x7D6`
as FD frames when it sees the raw BMS frame go by (`cmd/dashboard/flag.go`).

The announcement echoes **the bytes that were on the wire**, not the Pi's configured
code. A BMS provisioned with the wrong code must show the wrong code; substituting
the expected value here would mask a mis-provisioned board and turn a loud fault into
one that only surfaces when a team's flag is rejected by the scoreboard.

The kernel gateway's `0x7D1`/`0x7D2` forwarding is left alone, so both forms reach a
contestant's tap and the two rules `ttos-reset` and `ttos-selftest` assert are still
the right count.

### Drive command format

```
 byte:  0    1    2    3     4     5      6       7
      +----+----+----+----+-----+-----+-------+-------+
      |   steps (u32 BE)  | dir | rpm | nonce | crc8  |
      +----+----+----+----+-----+-----+-------+-------+
      |<-------------- covered by crc8 ------>|
```

`dir` `0x01` forward / `0x02` reverse / `0x00` stop-and-clear. `steps` are **added**
to a drain buffer capped at 250; a direction change clears it.

`crc8` is CRC-8/SAE-J1850 (poly `0x1D`, init `0xFF`, xorout `0xFF`) over bytes 0–6
**keyed by a 16-bit Data ID that is never transmitted**, prefixed low byte first —
AUTOSAR E2E Profile 1 convention. Agreement verified across three implementations
(Go, Python, C++) against bytes captured off the wire.

A **6-byte legacy form** (bytes 0–5, no nonce or CRC) also exists and is what the
Pi's own control pad sends. See section 4 for why both exist.

---

## 3. Where every secret lives

| Value | Per car or fleet-wide? | Lives on | Contestant-visible? |
|---|---|---|---|
| WiFi SSID / PSK | **per car** | Pi (provisioned) | on the placard |
| Hostname | **per car** | Pi (provisioned) | yes |
| Console password | **per car** | Pi (provisioned) | no — operator only |
| VIN | **per car** | Pi (provisioned) | via DID `0xF190`, by design |
| ECU serial | **per car** | Pi (provisioned) | via DID `0xF18C`, extended session |
| Fleet salt | fleet-wide | Pi (provisioned) → **served in the panel JS** | yes, deliberately |
| **Data IDs L/R** | **fleet-wide** | Pi (provisioned) | **no — this is Challenge 3** |
| **Codes C1/C2/C3** | **fleet-wide** | Pi + BMS firmware | emitted by the car on solve |

**Changed 2026-08-03: Data IDs and codes are fleet-wide, not per car.** Reason: a
car dying mid-challenge used to cost that team their work, because the values they
recovered did not apply to a replacement. Uniform values make any car a drop-in
spare. Cost: a code that is overheard now works on any car — covered by the judging
path (section 7), which is car-level and server-side.

L and R Data IDs still differ **from each other**. They are separate binaries
either way, since the CAN id differs.

---

## 4. Node provisioning, and where protection is enforced

**Nothing per-car is compiled into firmware.** There is one motor binary and one BMS
binary for the whole fleet. The Pi is the only thing that carries per-car data.

```
SETUP (automatic, first boot with a provisioning file present)
    → Pi bursts Data IDs, unlock codes and detector thresholds on 0x101 for ~6 s
    → nodes latch them and WRITE THEM TO FLASH
    → Pi records that it is done, and never repeats it

RUNTIME (competition)
    → nodes read from flash at boot; NOTHING is transmitted
    → a provisioned node IGNORES further config frames
    → the relay refuses to transmit 0x101 or 0x100 at all
```

Provisioning happens **automatically on the first boot after the car is
provisioned** — drop the config on the boot partition, power on, done. Nobody shells
into eight cars. `ttos-provision-nodes` exists only for the case where a node is
replaced afterwards.

**Why it is one-shot rather than periodic.** An earlier version
broadcast the set at 1 Hz forever and filtered it out of the relay's read path. That
put the value Challenge 3 exists to recover permanently on the bus a contestant is
attacking, with a single Pi-side filter between them and it. It happens once, at
setup, with nobody listening — and not on every restart, which during an event is
whenever a team asks for a power cycle.

**Why a provisioned node refuses reconfiguration.** Otherwise anyone reaching the
drive bus could hand the motors a Data ID they already knew and forge freely,
collapsing Challenge 3 into "get relay access". Re-provisioning means erasing or
reflashing the node — physical access, deliberately.

**Codes are write-once; detector TUNING is not.** The BMS accepts record type 0x20
(pivot rpm, pair window, C3 count and window) even when already provisioned, and
persists it. The whole config handler used to be refused once configured, which
meant a pivot-rpm retune silently could not reach the node: the burst went out, the
tool reported success, and the BMS kept the old value. That divergence is not
cosmetic — C3's discriminator is *same direction AND an rpm the pivot never uses*,
so a Pi pivoting at 150 against a BMS still believing 75 lets a team replay captured
pivot frames straight into the C3 code with no forgery at all. Leaving tuning open
is safe because 0x101 is refused by the relay's SEND path and is not in the C2
bridge allowlist, so no contestant-reachable path can inject it.

**A node reports what it holds.** The BMS prints a `cfg:` line on its serial port
every 5 s — configured or not, a fingerprint of the stored codes (not the codes
themselves; contestants can reach that USB port), and the tuning values. Boards on
one fleet share codes, so they must share a fingerprint; an odd one out is a board
to erase. It is periodic rather than printed at boot because these are native-USB
boards and a reset drops the CDC connection before a monitor can attach.

**Unconfigured is permissive.** A node with nothing stored accepts the unprotected
6-byte command, because an unprovisioned car must still drive — a hard requirement,
and a car that will not move until provisioned is useless during setup.

That is fail-open, so **the Pi's inbound gates validate protection independently**.
Contestants have exactly two routes to the drive bus and the Pi owns both: the 5 s
C2 bridge window and the C3 relay. Both drop unprotected or bad-CRC frames silently.
The two layers cover each other — a node that missed its config still cannot be
driven by a contestant, and a mistake in a gate still leaves the node enforcing.
Neither is load-bearing alone.

Both gates **answer uniformly**. The relay says `OK queued` whether or not it
forwarded, because answering "bad CRC" would be a free oracle: a contestant could
sweep the protection byte and read the reply instead of recovering the Data ID. The
only feedback is whether the car moved.

## 5. The gateway

In-kernel `cangw`, installed at boot, two rules, nothing inbound:

```
cangw -A -s candrive -d candiag -f 7D1:7FF     flag frames out
cangw -A -s candrive -d candiag -f 7D2:7FF
```

**Nothing else crosses in either direction.** Drive traffic must not go outbound or
contestants could build the C2 corpus by passive sniffing, which would collapse C2
from "interact with the car, then compose" into "watch and replay". The sanctioned
corpus source is the snapshot DID instead.

The C2 inbound bridge is *not* a cangw rule — it is Go, because installing kernel
gateway rules needs `CAP_NET_ADMIN` and `ttos-dashboard` is the one process
contestants can reach over the network.

**One writer, one bus.** Every frame the Pi puts on the drive bus — heartbeat, node
config, the C1 pivot, the C2 bridge, the C3 relay and the operator's control pad —
goes through a single socket. A second, config-gated socket existed for the control
pad until 2026-08-04; provisioning emptied that config on every competition car, so
the gate disabled nothing except the operator's own panel, including the e-stop.

**The 12 V rail is part of the sanctioned path.** The stepper drivers are dead
without it and the BMS boots with it off, so the C1 routine energizes it (`0x115`
`[0x01]`) *before* commanding the wheels. Nothing else in shipping code did, which
meant a freshly booted car ran a perfectly valid pivot into unpowered drivers and
returned the flag anyway — a solve with a motionless robot.

---

## 6. The three challenges

The three challenges are a deliberate progression through how a modern vehicle is
actually attacked: **talk to it, then trick it, then take it over.** Each one teaches
a technique that transfers directly to real cars, and each depends on the one before
it — not by an artificial gate, but because the later work genuinely needs what the
earlier work produced.

The car starts locked. Its operator console shows battery, 12 V state and network
status, but no raw bus traffic and no driving controls. The only way in is the
diagnostic connector, which is exactly the situation a technician or a researcher
faces with an unfamiliar vehicle.

---

### Challenge 1 — Discovery

*"There is a computer in this car. Find it and make it do something."*

**The real-world skill.** Every modern vehicle carries a diagnostic protocol called
UDS — Unified Diagnostic Services, ISO 14229 — the language behind every scan tool,
every dealer tester, and every emissions check. It is how a workshop reads a fault
code, how a VIN is confirmed without crawling under the windscreen, and how an
actuator is commanded during a service procedure. Learning to speak it unassisted,
without a commercial tool doing it for you, is the entry point to all vehicle
diagnostics work.

**What the contestant faces.** They connect an adapter to the diagnostic bus and see
*nothing*. This is correct and it is the first thing to understand: a diagnostic port
is not a firehose. Unlike the vehicle's internal networks, which chatter constantly,
a diagnostic bus is silent until something asks a question. There is no traffic to
capture and reverse-engineer here. You have to speak first.

**The work.** UDS is request–response. A tester sends a service identifier and the
ECU answers. The two that matter here:

- **ReadDataByIdentifier (`0x22`)** — "tell me the value of this named item." The
  names are 16-bit Data Identifiers, and a handful are standardised across the whole
  industry. `0xF190` is the VIN on essentially every car built in the last fifteen
  years. That is the contestant's first foothold: a real identifier, on a real
  protocol, returning a real value.

- **RoutineControl (`0x31`)** — "run a procedure." This is the service a workshop
  uses to bleed ABS brakes, cycle a window motor through its learn procedure, or
  sweep an actuator through its range. It is the part of UDS that *makes the car do
  things* rather than merely report on them.

Having found the VIN, the contestant sweeps for other identifiers and finds two more
in the manufacturer-specific block. Then they go looking for routines. The routine
identifiers sit in a small contiguous group, so finding one makes its neighbours the
obvious next probe — the puzzle is meant to be what the routines *do*, not a
brute-force search of 65,536 numbers.

**The payoff.** One of those routines is a pivot: the car spins in place, one wheel
forward and one back, through a fixed arc. It is unmistakable, it is physical, and
it happens because the contestant asked for it in the car's own language. The
routine's response carries the Challenge 1 code.

**Why the flag is in the response and not somewhere else.** UDS routines return a
"routine status record" — whatever the ECU wants to report about what it just did.
Putting the code there means the contestant has to correctly parse a real protocol
response, not just observe that something moved.

---

### Challenge 2 — Sessions, and the door that is not the door

*"The obvious way in is locked. Find the way that is actually open."*

**The real-world skill.** Diagnostic access is layered. An ECU boots in a default
session where it will answer harmless questions, and refuses anything consequential.
Ask it properly — `DiagnosticSessionControl (0x10)`, extended session — and a larger
surface opens up. This is the single most common stumbling block for people new to
UDS: they send a valid request, get a refusal, and conclude the feature does not
exist.

It does exist. The ECU told them exactly what was wrong, in a **negative response
code** — a one-byte reason attached to every refusal. Reading an NRC and acting on it
is the most transferable habit in diagnostics work, and it is what this challenge
teaches.

**What the contestant faces.** One of the identifiers found in Challenge 1 — the ECU
serial number, `0xF18C` — refuses to answer. The refusal is not a silence or an
error; it is `serviceNotSupportedInActiveSession`. The car is saying *"not like
this."* Change session, ask again, and it answers.

**The misdirection, and why it is fair.** Among the routines is one plainly named for
enabling diagnostic bridging. It looks like precisely what a contestant would want,
and it **always refuses** — `securityAccessDenied`, in every session, under every
condition. That door never opens.

The routine beside it is a self-test. It sounds like housekeeping. But an actuator
self-test genuinely needs the diagnostic tester to be able to command the actuators
while it runs, so for **five seconds** it opens a path from the diagnostic bus to the
vehicle's internal bus.

That contrast is the lesson: **one refusal says "wrong conditions", the other says
"never".** Distinguishing them is real diagnostic reasoning. And the security lesson
underneath it is one that recurs constantly in real vehicles — the dangerous
capability is rarely behind the door labelled with its name. It is a side effect of
something that sounds routine.

**The composition.** Now the contestant can inject onto the internal bus, but only
briefly, and only two message types. They cannot invent commands: the car's motor
controllers reject anything not carrying a correct **message protection field** — a
checksum keyed by a value that is never transmitted. This is not invented for the
challenge; it is AUTOSAR End-to-End protection, and it is on real safety-relevant
buses precisely to stop this kind of injection.

But they do not need to invent anything. Another identifier returns a **snapshot of
the last commands the car sent to each wheel, protection field intact.** Run the
pivot, read the snapshot, and you have a genuine, still-valid left-wheel command and
a right-wheel command.

The pivot drives the wheels in *opposite* directions. So the contestant takes the
captured frames and sends both wheels the one that drives them the *same* way. They
have composed a command the car has never issued, from parts it handed them, without
breaking any cryptography at all.

The car lurches sideways. It should not be able to do that while locked, and the
battery management module — watching the internal bus — notices and emits the
Challenge 2 code.

**Why the snapshot exists.** The gateway deliberately never forwards internal traffic
outward, so a contestant cannot simply listen and collect commands. Without a
sanctioned source of valid frames, Challenge 2 would collapse into passive sniffing
and replay. Making them *invoke* a routine and *read back* what it sent is the
difference between watching a car and interacting with one.

---

### Challenge 3 — Wireless takeover

*"Stop borrowing the car's own messages. Write your own."*

**The real-world skill.** This is the shape of every headline vehicle compromise of
the last decade: a network-facing service, credentials derived from data the vehicle
will tell you if you ask, and message protection that turns out to be a checksum
rather than a signature. Nothing here is exotic. That is the point.

**Finding the door.** The car runs a telematics service on its own WiFi. It is
discoverable two ways — a diagnostic identifier returns the host and port, and the
console mentions the interface once Challenge 2 is solved. Two routes deliberately:
a challenge whose entrance can only be found one way fails completely for a team that
misses that one way, and guessing a port number is not a skill worth testing.

**The credential.** The service wants a key. The key is derived from the vehicle's
own identity:

```
key = SHA-256( VIN : ECU serial : fleet salt ), first 16 hex characters
```

Every input is obtainable. The VIN came from Challenge 1. The serial required the
session work from Challenge 2. And the transform itself is **sitting in the console's
JavaScript**, served to any browser that loads the locked page.

**That is the vulnerability, and it is a real one.** Authentication logic shipped to
the client is among the most common findings in connected-vehicle assessments —
companion apps and in-car browsers routinely contain the algorithm that protects the
thing they talk to. Shipping it here is deliberate: it makes the challenge about
*recognising* that pattern rather than guessing at concatenation order, separators
and truncation. A contestant who views source has the answer; a contestant who does
not will not brute-force 64 bits.

It also enforces the ordering honestly. The transform is worthless without the VIN
and the serial, and the serial cannot be read without knowing how to change
diagnostic session. Challenge 3 needs Challenge 2's skill, not merely its flag.

**Now the protection matters.** Authenticated, the contestant has a raw path onto the
vehicle's internal bus — and this is where Challenge 2's borrowed frames stop being
enough. Replaying a captured command drives the car in a fixed arc at a fixed speed.
To actually *drive* it, they must construct commands the car has never sent, which
means producing a correct protection field, which means recovering the key that
generates it.

**What "recovering the key" actually means here**, and it is worth being precise
because the judging depends on it. The checksum is linear over GF(2). That means a
fixed-length key contributes a constant offset to every result, independent of the
message. A contestant does not recover *the* key — they recover a **256-member
equivalence class**, every member of which produces byte-identical checksums. Forgery
works perfectly without ever identifying the "true" value, and extra captured
messages give no further information. The real work is identifying the *algorithm* —
which checksum, over which bytes, in which order — not extracting a secret.

**The finish.** Driving the car under sustained forged commanding is a signature the
battery management module recognises, and it emits the Challenge 3 code. Redeeming it
unlocks full manual control of the vehicle from the console — which is, appropriately,
the same thing the attack achieved.

---

### Why the three cannot be short-circuited

The separation between Challenge 2 and Challenge 3 is **mechanical, not a policy
decision**. Challenge 2's composed attack reuses captured frames, which structurally
carry the speed the pivot routine uses. Challenge 3's detector only fires on a speed
that never appears in the car's own legitimate traffic. So no amount of replaying can
accidentally produce the Challenge 3 code — a contestant who has not learned to forge
cannot stumble into it, and one who has does not need to.

## 7. Detection, arming, and judging

Detection lives in **BMS firmware**, watching the drive bus it is already on.

| | condition |
|---|---|
| **C2** | both motors commanded the **same direction** within 250 ms |
| **C3** | 15 consecutive same-direction commands within 3 s at rpm ≠ `PIVOT_RPM` |

Both are gated by the **arm mask** in heartbeat byte 1 — bit 0 = C2 armed, bit 1 =
C3 armed. **Positive arming**: any failure (stale heartbeat, short frame, no
heartbeat) yields mask 0 and leaves detection **disarmed**. A dead station is
recoverable; a silently leaked flag is not.

The mask is driven by the **car-level** record of tiers redeemed since last reset,
*not* by the browser session's tier. If it were session-scoped, opening a second tab
would silently re-arm detection mid-event and the car would leak codes during
ordinary driving.

**A reboot returns a car to LOCKED.** Every piece of challenge state — session
tiers, the car-level unlock record, the C2 bridge window — is in memory and nothing
persists it, so power-cycling is a full reset. A cookie held from before the reboot
is worthless: the client still has it, but the server has forgotten the token. The
only thing written to disk is the node-provisioning marker, which is not challenge
state. Verified on hardware, and asserted by `test-panel.py --reboot` (P9) so that it
stays true if anyone later persists state to survive a crash.

**There is no judging endpoint.** One existed briefly and was removed: it was never
asked for, it was unauthenticated on the AP so it handed contestants a
solved/not-solved readout, and the "sequence number" it reported was the relay's log
line counter dressed up as something a judge would verify against. Judging is a team
showing you the code they recovered.

The car-level record itself stays, because it is not a judging feature — it is what
`armMask()` reads.

**Reset:** `sudo ttos-reset` on the car clears every unlock, re-arms the detectors,
and reloads the gateway. Runnable from the serial console with no laptop, because
between rounds that is all an operator has. **It verifies before it declares.** It
used to print "This car is LOCKED and ready for the next team" and exit 0
unconditionally — so a failed gateway reload handed the next team a car that boots,
serves the panel, answers every diagnostic request and pivots correctly, and can
never award a code, because `0x7D1`/`0x7D2` no longer have a route to the
diagnostic bus. It now checks the dashboard, the gateway and the rule count, and
exits non-zero with the diagnosis if any of them is wrong.

**Stopping a car is electrical.** The motor sketches drain their step buffer on
`stepsLeft > 0` alone; `heartbeatOK()` drives the status LED and nothing else. Pull
the Pi, kill the service or cut the bus and the wheels finish what they have — up to
250 steps, which at an attacker-chosen `rpm=1` is 75 seconds. Do not design anything
around heartbeat loss halting the wheels; that claim was written into three shipping
places and was never true. The e-stop therefore drops the 12 V rail **first**, ahead
of both motor frames, and is best-effort across all three rather than stopping at
the first transmit error — the error case is a contestant saturating the drive bus
through the relay, which is exactly when someone reaches for the button.

---

## 8. Panel tiers

One embedded bundle, no tier-dependent assets. Gating is server-side, re-checked
**per SSE event** — a stream opened at tier 3 stops carrying tier-3 payloads the
moment the session lapses.

| Tier | Unlocked by | Adds |
|---|---|---|
| Base | — | indicators, bridging tell, docs, flag entry, `deriveServiceKey()` |
| 1 | C1 code | DIAG-bus frame tab |
| 2 | C2 code | DRIVE-bus frame tab, telematics named outright |
| 3 | C3 code | full drive controls; detectors stand down |

Sessions are `crypto/rand` tokens in an `HttpOnly` cookie, server-side tier map,
10-minute **sliding** idle. In memory, so a service restart clears every unlock.

**Tier 3 is the whole of drive authority — there is no config switch beside it.**
The dashboard has exactly one writer to the DRIVE bus, shared with the heartbeat,
node provisioning, the UDS routines, the C2 bridge and the C3 relay. A second,
config-gated socket for the control pad existed until 2026-08-04 and was removed:
provisioning emptied `TTOS_DASH_DRIVE` on every competition car, which read as a
read-only safety gate but gated nothing else on that bus, so the only thing it
disabled was the operator's own panel — **including the e-stop**, whose frames
were discarded while the handler still answered `{"ok":true}`.

The e-stop (`stop`) is exempt from the tier gate by design: it must work from a
locked panel, a lapsed session, or a judge's phone. It closes the C3 bridge, zeroes
both step buffers and drops the 12 V rail. `/api/control` now reports failure when
frames do not reach the bus, and `test-panel.py` asserts the **wire** (P6c, P6d),
not the HTTP status — an HTTP 200 is not propulsion.

`stop` on `/api/control` is **ungated on purpose** — an e-stop behind an unlock is
not an e-stop.

---

## 9. What is flashed where

| Target | Count | Unique? | Build |
|---|---|---|---|
| Pi image (`.wic`) | 8 | **identical** | `./build.sh` |
| `ttos-provision.conf` | 8 | **per car** | `provisioning/ttos-provision-carNN.conf` |
| BMS firmware | 8 boards | **identical binary** | `./build.sh <fqbn> TinytrekBMS` |
| Motor firmware | 16 boards | **identical binary** | `./build.sh <fqbn> TinytrekLMotor` / `RMotor` |

No build-time car id anywhere, and no per-car setup command. **The entire per-car
difference is one file on the Pi's boot partition** — drop it, power on, and the car
provisions itself and its three nodes.

That file must be named exactly `ttos-provision.conf`; the car checks
`/boot/firmware/` and `/boot/` and nowhere else. A file under any other name is not
found and the car boots into factory mode with an open `TTOS-TEST` AP and no
challenge identity, silently. `render-fleet.py` emits `flash/car-NN/` directories
with the file already correctly named so there is nothing to rename while
flashing.

It also emits `TTOS_SSH_AUTHORIZED_KEY`. A fresh card wipes the rootfs and with it
any key installed by hand on the previous one, and every bench script uses
`ssh -o BatchMode=yes` — so without this a reflashed car is unreachable to the whole
harness until someone copies a key over, eight times, after every reimage. The key
comes from `TTOS_OPERATOR_SSH_KEY` in the render environment and from nowhere else:

```sh
TTOS_OPERATOR_SSH_KEY="$(cat ~/.ssh/id_ed25519.pub)" ./render-fleet.py out/
```

When it is unset the generator writes a comment into the conf saying so, and says
it again on stdout, rather than silently omitting the line. An event car should
carry the key of a machine that will actually be at the event and not the build
host's, and there is deliberately no filesystem fallback that could pick the
wrong one — whoever's key ships is whoever ran the command.

---

## 10. Known gaps

- **Motor stutter unexplained.** Bus contention is ruled out with data measured on
  the drive controller itself (0.34% load, zero bus errors, command-stream stdev
  1.5 ms over 160 frames). Prime suspect is the browser-driven keepalive over WiFi,
  still unmeasured. Note the earlier version of this measurement read its error
  counters from the wrong interface and reported zeros for a controller it never
  opened; the numbers above are from the corrected tool.
- **Pivot at 75 rpm is unconfirmed mechanically.** 250 pps should clear the
  resonance band; only a real drivetrain can say whether it is smooth.
- **One team can disarm another car's detectors.** Codes are fleet-wide, PSKs are on
  placards in the same room, and `/api/flag` needs no prior tier — so a team can
  paste a code into a neighbouring car's panel and stand its detectors down. The
  victim then solves C2 correctly and sees nothing. Recoverable with `ttos-reset`,
  so the cost is a lost round rather than a lost event, and it requires deliberate
  sabotage. It is the one place one team's action reaches another team's challenge,
  and it is a consequence of the fleet-wide decision in section 3 rather than a bug.
- **A C1 solve leaves no trace outside journald.** The car-level record tracks C2 and
  C3 only, because its job is driving the arm mask and C1 has no detector. Nothing
  reads it out, by design.
- **Placards not written.** SSID, PSK, car id, the DIAG bus parameters, "CAN FD
  required", the panel URL, and "use Safari or Firefox — Chrome force-upgrades
  port 80".
- **No judging brief for the event.** `judge-packet.md` was deleted 2026-08-04
  rather than repaired: it listed per-car unlock codes after the fleet went uniform,
  and it named an exact Data ID when a correct Challenge 3 solve recovers a
  256-member equivalence class and cannot identify the true value. `WALKTHROUGH.md`
  section 4 has the substance if a printed sheet is wanted, including what a correct
  C3 solve can and cannot be asked to produce.
- **The remaining six cars are unflashed.** Cars 01 (bench DUT) and 02 are on the
  current image and firmware.

---

## 11. Walkthrough

`WALKTHROUGH.md` is the operator's solve of all three challenges end to end, with
the reasoning at each step. It is the fastest way to check that a car is genuinely
solvable, and it is the reference for what a contestant is expected to do.

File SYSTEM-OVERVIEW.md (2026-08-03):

> **Bus roles, challenge design and the CTF architecture live in
> [ARCHITECTURE.md](ARCHITECTURE.md), which is the source of truth.**
> DRIVE is `can0`, DIAG is `can1`. Anything below that disagrees is stale.

# TinyTrekOS CTF — System Overview

**Status as of 2026-08-02.** Baseline vehicle platform is **complete and working**:
boots reliably, both CAN buses up, WiFi AP, operator dashboard, and the dashboard
drives a real car. **No challenge logic exists yet** — that was deliberate. This
document is the handoff for designing the CTF challenges.

Repo: `~/ttos-ctf` (ported from the public `sixvolts/TinyTrek`, not a fork).

---

## 1. Hardware

| Part | Detail |
|---|---|
| Compute | Raspberry Pi 4, 2 GB |
| CAN | Waveshare **2-CH CAN FD HAT Rev2.1**, "Mode A" (two independent SPI buses), MCP2518FD ×2, 40 MHz oscillator |
| Motor nodes ×2 | **Adafruit QT Py SAMD21** + MCP2515 (`CAN.setPins(3, 0)`), stepper drivers |
| BMS node | **Adafruit Feather RP2040 CAN** (built-in MCP2518FD), drives a 12 V relay, reads pack voltage |
| Battery | 3S pack. 8.4 V = 0 %, 12.3 V = 100 %. Sense = 120 kΩ/40.2 kΩ divider (0.5 %) → BMS `A1` |

Pi ↔ nodes are connected **only** by CAN. There is no other link.

---

## 2. CAN buses — read this carefully

Two buses, and **the naming is inverted relative to the original design doc**:

| Interface | Config | What is actually on it |
|---|---|---|
| `can0` | **CAN FD**, 500 kbit arbitration / 1 Mbit data | **DIAG bus.** No permanent nodes — terminates at the contestant side tap. Writes fail `ENOBUFS` until an adapter is plugged in (a lone node gets no ACK), which is correct for a diagnostic port. |
| `can1` | **Classic CAN 2.0, 500 kbit** | **DRIVE bus** — both motors + BMS. Verified 2026-08-01. |

**Consequences for challenge design:**

- Anything that drives the car must use **`can1`**. `TTOS_DASH_DRIVE=can1`.
- **The DRIVE bus is classic CAN 2.0 and must stay that way.** Every node on it is
  classic-only — the motor nodes are MCP2515, which has no FD support at all. An FD
  frame there is a form error: the nodes go error-passive, then bus-off, and
  propulsion stops. `can1` was briefly configured `FDMode=yes` with a 1 Mbit data
  rate, which bought nothing (no node could use it) while leaving the Pi able to
  transmit a frame that would take the drivetrain offline. Removed 2026-08-02 — with
  FD off, the controller **cannot** emit one even by mistake. `ttos-selftest` fails
  if `can1` ever comes up in FD mode again.
- The gateway still forwards classic frames only (no `-X`), which is now redundant
  protection rather than the sole line of defence.
- Interface naming is pinned by `10-can0.link` / `10-can1.link` (matching SPI paths
  `platform-fe204000.spi*` → `can0`, `platform-fe215080.spi*` → `can1`) so names are
  stable across boots. Swapping those two `Path=` tokens would rename the buses if
  you'd rather match the original doc.

### Protocol (all on the drive bus)

| ID | Dir | Payload | Rate |
|---|---|---|---|
| `0x100` | Pi → nodes | `[seq][flags]` — **heartbeat**, "Pi alive and in control" | 5 Hz |
| `0x111` | Pi → L motor | `[steps:uint32 BE][dir][rpm]` | on demand (~6.7 Hz while held) |
| `0x113` | Pi → R motor | same | same |
| `0x115` | Pi → BMS | `[0x01]` = 12 V on, `[0x02]` = off | on demand |
| `0x116` | BMS → all | `[v_hi][v_lo][pwr][flags]` — **beacon**: pack mV (uint16 BE), `pwr` `0x01`=rail on/`0x02`=off (**actual** state), `flags` bit0 = LVC latched | 5 Hz |

Motor semantics: `dir` `0x01`=forward, `0x02`=reverse, `0x00`=stop/clear. `steps` is
**added** to a capped buffer (`STEPS_MAX`=250) that the node drains as it steps, so
motion tolerates dropped frames. `rpm` sets speed (100 straight / 50 turns).
Differential drive: forward = L01/R01, turns use opposite directions.

**No authentication on any of this.** Any device on the bus can command motion or
cut power. That is the intended CTF attack surface.

---

## 3. Status LEDs (system-state visibility)

Every node's onboard NeoPixel reports the health of the **whole chain**.

**Motor nodes** (QT Py SAMD21, `PIN_NEOPIXEL`=11, no power-gate pin):

| LED | Meaning |
|---|---|
| 🟢 solid green | READY — heartbeat + 12 V both good, idle |
| 🟡 solid yellow | ACTIVE — propulsion running |
| 🔴 double-blink | no Pi heartbeat (12 V fine) |
| 🔴 regular blink | no 12 V active (heartbeat fine) |
| 🔴 solid | both missing; also the power-on state → node isn't receiving CAN at all |

**BMS node** (Feather RP2040 CAN): blink = 12 V relay (solid off / slow blink on),
colour = battery band (green ≥50 %, amber 25–50 %, red <25 %), **fast-blink red** =
low-voltage cutoff latched.

Note: the heartbeat only transmits when driving is **enabled**, so a read-only
(provisioned) car's motors double-blink red by design — not a fault.

---

## 4. Networking

| | |
|---|---|
| AP subnet | **`192.168.244.0/24`**, car at **`.1`**, DHCP pool `.10–.59` |
| Default route | **Not offered** (`EmitRouter=no`) — joining the car AP won't hijack a client's internet |
| Provisioned AP | Per-car SSID + WPA2-PSK, 5 GHz non-DFS channel, low TX power (500 mBm ≈ 5 dBm, ~1–2 m range) |
| Factory AP | **`TTOS-TEST`**, **open, no password** (unprovisioned cars only) |
| Ethernet | `eth0`/`end0`, DHCP + link-local; optional static via provisioning |

**Listening services:** dashboard **TCP 80** (on the AP address), **sshd TCP 22**
(socket-activated; password auth on, root login denied).

> `socketcand` (TCP 29536, bridged both buses) was **removed 2026-08-02**. It was an
> unauthenticated network path to the DRIVE bus, and it would not have worked as a
> contestant-facing diagnostic path anyway: it is only a front-end to the Pi's own
> `can0` controller, so with no physical tap attached there is no second node to ACK
> and nothing transmits. Diagnostic access is the **physical side tap only**.

> Chrome force-upgrades `http://192.168.244.1` to HTTPS and won't fall back. Use
> Safari/Firefox, or disable "Always use secure connections". Port 80 was a
> deliberate choice (clean URL).

---

## 5. Operator dashboard

Go service (`ttos-dashboard`), stdlib-only, static aarch64 binary, embedded UI.

- `GET /` — operator console UI (TU navy + gold, Shojumaru logo)
- `GET /events` — SSE stream: `frame` / `log` / `status` events
- `GET /api/info` — ifaces, car id, client keepalive interval
- `POST /api/control` — `{"cmd": "forward|back|left|right|cw|ccw|stop|coast"}`

UI: tabbed console (Debug + one tab per bus, live frames with decoded notes),
indicator panel (12V ACTIVE, battery %, sensors, WiFi/Ethernet), control pad
(hold-to-drive; STOP cuts the 12 V rail).

**Safety gate:** `TTOS_DASH_DRIVE` (in `/etc/default/ttos-dashboard`) is **empty by
default** = read-only; the UI validates and logs but transmits nothing. Set to
`can1` + restart to enable driving. Factory mode sets it automatically.

Battery gauge applies a **load-compensation offset** (`+1000 mV` default): the pack
reads ~1 V lower under the Pi's steady load, so the gauge adds it back before
mapping 8.4–12.3 V → 0–100 %. The 12 V indicator reflects the **BMS's real reported
state**, not the commanded one (so it tells the truth during an LVC cutoff).

All tuning is live via `/etc/default/ttos-dashboard` (rpm, keepalive, step chunk,
battery range/offset, heartbeat period) — no rebuild.

---

## 6. Boot, provisioning, and factory mode

One image for the whole fleet; per-car identity applied on first boot from
`/boot/ttos-provision.conf` (FAT partition), then **consumed and wiped**.

Provisioning sets: hostname, car ID, WPA2 SSID/PSK/channel/country/TX power,
`ttos` password (crypt hash — plaintext is rejected), optional SSH authorized key,
optional static Ethernet, and **regenerates per-car SSH host keys**. Marker:
`/etc/ttos/provisioned`. Log: `/etc/ttos/provision.log` (persistent, one line per
boot decision). Malformed file = **fail loud** (banner on console + `/etc/issue`),
and the file is left in place to be fixed in the field.

**Factory / test mode** — when *no* provisioning file is present:
open `TTOS-TEST` AP, driving enabled (`can1`), console login **`ttos` / `ttos`**,
loud banner. Marker `/etc/ttos/factory`. Provisioning overwrites all of it and
re-locks the car. Intended for bench hardware bring-up only.

**Rootfs auto-expand** (`ttos-growfs`) runs *after* provisioning and only on a
provisioned car; grows the root partition + ext4 to fill the SD card, once.

---

## 7. Security posture (baseline — pre-challenge)

- `root` **locked**, no login on any path. Ops log in as `ttos` and `sudo` (wheel).
- U-Boot **removed** — an interruptible bootloader prompt on the serial console is
  a password-free root shell.
- Serial ops console on the **GPIO UART** (`ttyAMA0`, internal header), password
  gated. Plus a USB CDC-ACM console (`g_serial` → `ttyGS0`) for laptop access.
- SSH: `PermitRootLogin no`, password auth **on**, per-car host keys.
- Provisioning secrets: `/etc/ttos/provision.src` mode 600; FAT copy shredded.

**Deliberate weaknesses available as challenge material:** unauthenticated CAN,
open factory AP, password auth on SSH, no bus-level access control, `12V ACTIVE` as
a physical/observable state.

---

## 8. Build

```bash
cd ~/ttos-ctf && ./build.sh            # kas + bitbake in a pinned container
```

Yocto **scarthgap**; layers `poky`, `meta-openembedded`, `meta-raspberrypi`,
`meta-tt-ctf` (ours). Machine `ttos-ctf-hw` (RPi4-64 derived). Output:
`~/yocto/tmp-glibc/deploy/images/ttos-ctf-hw/ttos-ctf-image-ttos-ctf-hw.rootfs.wic`
(~532 MB). Two images: `ttos-ctf-image` (production) and `ttos-ctf-image-dev`
(bench, debug-tweaks — **never** flash to competition cars).

Node firmware lives in `firmware/` with **vendored** libraries (`CAN`,
`Adafruit_NeoPixel`); built/flashed from a laptop via `firmware/build.sh` or the
Arduino IDE. FQBNs: motors `QT Py SAMD21`, BMS `rp2040:rp2040:adafruit_feather_can`.

On-device health check: **`sudo ttos-selftest`** (one command, covers boot, CAN,
AP, provisioning, accounts).

---

## 9. Gotchas that cost real time

- **Never order a `multi-user.target` unit `Before=sshd.socket`.** It creates a
  systemd **ordering cycle**; systemd breaks it by deleting a job at random, so a
  unit silently never runs — non-deterministically. This killed the AP on ~half of
  boots. Diagnostic: enabled unit at `inactive (dead)` with **zero** `journalctl -u`
  entries → check `journalctl -b | grep -i 'ordering cycle'` first.
- Minimal rootfs is **busybox**: `head`/`tail` need `-n N`; `ip`/`ss` are in `/sbin`
  (not in the `ttos` PATH — use `sudo`).
- journald is **volatile** — only the current boot is visible. Consider
  `Storage=persistent` before chasing another intermittent boot bug.
- The Pi has **no RTC**; timestamps are wrong until NTP syncs (there's no internet
  on the AP), so log dates can read months off.
- Don't let automation rewrite operator config every boot — factory mode used to
  clobber `TTOS_DASH_DRIVE` on each boot and silently broke driving.

---

## 10. Open items

- **Bus naming**: drive bus is `can1` (FD-configured) while the doc says `can0`.
  Leave as-is / swap `.link` files / rewire — decide before challenges assume a layout.
- **Debug access for the AI agent**: arcana is wired-only and can't join the car AP.
  Options discussed, none implemented: Ethernet + SSH (cleanest), persistent
  journal, USB serial to arcana, on-device support-bundle command.
- **Left motor stutter**: intermittent, survived several drive-model rewrites;
  suspected node/wiring rather than software. The new status LEDs are intended to
  localise it.
- **Sensors**: U-Sonic / Camera indicators are placeholders — no telemetry defined.
- **No challenge content exists yet.**

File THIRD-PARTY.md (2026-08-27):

# Third-party components

The MIT license at the root covers the original work in this repository. It does
**not** cover the third-party components vendored into the tree — copied in
rather than pulled by a package manager — which each keep their own license,
including LGPL-licensed Arduino libraries under `firmware/` and an OFL-licensed
font in the dashboard's web assets. They are listed here so [LICENSE](LICENSE)
is not mistaken for a blanket claim over the whole tree.

Nothing here is modified from upstream unless the notes say so.

## Arduino libraries (`firmware/`)

The three sketch folders — `TinytrekBMS/`, `TinytrekLMotor/`, `TinytrekRMotor/` —
each carry a flat copy of their libraries, because the Arduino IDE compiles a
sketch folder as a unit. The same library therefore appears up to three times.

| Component | Files | Upstream | License |
|---|---|---|---|
| Adafruit NeoPixel | `Adafruit_NeoPixel.{cpp,h}`, `Adafruit_Neopixel_RP2.cpp`, `esp.c`, `esp8266.c`, `kendyte_k210.c`, `rp2040_pio.h` | [adafruit/Adafruit_NeoPixel](https://github.com/adafruit/Adafruit_NeoPixel) | **LGPL-3.0-or-later** |
| arduino-CAN | `CAN.h`, `CANController.{cpp,h}`, `MCP2515.{cpp,h}`, `ESP32SJA1000.{cpp,h}` | [sandeepmistry/arduino-CAN](https://github.com/sandeepmistry/arduino-CAN) | MIT (© Sandeep Mistry) |
| FlashStorage / FlashAsEEPROM | `FlashStorage.{cpp,h}`, `FlashAsEEPROM.{cpp,h}` (SAMD21 motor nodes only) | [cmaglie/FlashStorage](https://github.com/cmaglie/FlashStorage) | **LGPL-2.1-or-later** (© Arduino LLC) |

The LGPL components are used as libraries linked into the node firmware and are
redistributed here unmodified, with their license headers intact.

## Web assets (`meta-tt-ctf/recipes-apps/ttos-dashboard/files/src/cmd/dashboard/web/`)

| Component | File | Upstream | License |
|---|---|---|---|
| Shojumaru | `shojumaru.ttf` | [Google Fonts](https://fonts.google.com/specimen/Shojumaru) | SIL Open Font License 1.1 |

The font is bundled rather than linked because the car serves its panel from an
isolated WiFi AP with no route to the internet.

## Yocto layers (not in this repository)

`poky/`, `meta-openembedded/`, `meta-raspberrypi/` are cloned into the repo root
at build time by `kas` and are gitignored. They are upstream projects under their
own licenses (MIT for poky and meta-raspberrypi metadata; the built image's
package licenses are recorded in the Yocto license manifest under the deploy
directory).

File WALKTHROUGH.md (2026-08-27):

# TTOS CTF — full walkthrough

Solve all three challenges on a real car, by hand, with the reasoning at each step.

This is the operator's reference. Run it end to end on a car and you have proven that
car is genuinely solvable — which is not the same as the test suite passing, because
the suite drives the Pi's own interfaces and this drives the diagnostic port a
contestant actually has.

It is also the answer key, live flag codes and all. During an event, it does not go
on any machine contestants can reach. It is published here because the event it was
written for is over — if you are running these cars again, regenerate the fleet from
`provisioning/` first, and treat this file as compromised until you do.

**Companion:** `ARCHITECTURE.md` explains *why* the system is shaped this way.
This file is *what to do*.

---

## 0. What you need, and how to connect

| | |
|---|---|
| **A CAN FD adapter** | on the car's diagnostic port. **FD is not optional** — see below |
| **The car's WiFi** | SSID and PSK from the placard (or `provisioning/OPERATOR-SECRETS.md`) |
| **A browser** | Safari or Firefox. Chrome force-upgrades port 80 to HTTPS and the panel will look dead |
| **The tool** | `tools/ttos-ctf-tool.py` |

**The adapter must support CAN FD.** The diagnostic bus is 500 kbit arbitration /
1 Mbit data. A classic-only adapter will transmit every request successfully and
never receive a single answer, because every response in this system is longer than
8 bytes — VIN is 20, the pivot response 12, the snapshot 23. The failure looks
exactly like a dead car. If nothing ever answers, suspect this first.

Two wires. CAN is a differential pair and the diagnostic tap does not need a ground
reference: an isolated adapter's bus-side ground floats and self-references through
the pair.

### Connect and prove the link

```sh
# macOS, PEAK/SavvyCAN adapter (the default transport there)
python3 tools/ttos-ctf-tool.py probe

# Linux / arcana, SocketCAN
python3 tools/ttos-ctf-tool.py --transport socketcan --iface ttcardiag probe
```

`probe` sends a TesterPresent and waits for the car to answer. It retries three
times before declaring silence, because a single lost frame on first contact is not
a dead car and diagnosing it as one is expensive.

If it stays silent it will tell you which of the two situations you are in:
frames not being acknowledged at all (wiring, termination, CAN-H/L swapped) versus
frames going out fine and the car choosing not to answer. Those need completely
different fixes, which is why it distinguishes them rather than guessing.

### Join the car's WiFi and open the panel

```
SSID  ttos-car-NN          PSK on the placard
URL   http://192.168.244.1
```

You should see a **locked** panel: indicators, a bridging tell, docs, and a box to
paste a flag code. **No bus tabs.** That is correct — a locked panel showing live
drive-bus traffic would hand you Challenge 2's corpus by passive sniffing.

Leave this browser open. You will paste three codes into it.

---

## 1. Challenge 1 — Discovery

> *"There is a computer in here, and it will talk to you."*

**What the contestant is learning:** that a vehicle diagnostic port is a live command
interface, not a fault-code reader. This is the on-ramp; nothing here is defended.

### 1.1 — Establish a session and read the VIN

```sh
python3 tools/ttos-ctf-tool.py vin
```

On the wire that is UDS `ReadDataByIdentifier`:

```
tester → 0x7E0   22 F1 90
car    → 0x7E8   62 F1 90  "TTKTREK13TC000001"
```

`0xF190` is the standard VIN identifier and it is readable in the **default
session** — no unlock, no security access. That is realistic and deliberate: VIN is
not a secret, and a contestant needs one early win that requires nothing but asking
correctly.

Note the response is 20 bytes. This is the first thing a classic-only adapter fails
to receive.

**On a raw capture you will see one extra leading byte.** The service bytes above
are what sits *after* it:

```
7E8  03 7F 22 7F                      3 bytes of payload follow
7E8  06 50 03 00 32 01 F4             6 bytes
7E8  00 0C 71 01 02 01 31 44 38 ...   CAN FD form: 0x00, then the length 0x0C
```

Lengths up to 7 put the count in the low nibble (`0x0N`); anything longer uses the
CAN FD form — a `0x00` byte followed by the real length.

**This is not ISO-TP, and do not go looking for a transport layer.** The car borrows
ISO 15765-2's *single-frame header encoding* and nothing else, so that stock tooling
— `python-can-isotp`, CaringCaribou, a commercial tester — decodes these frames
without modification. There is no segmentation, no flow control, and no consecutive
frames: the server ignores multi-frame PCIs rather than answering them.

None is needed. CAN FD carries 64 bytes and the largest response in the system is the
snapshot at 23, so everything fits in one frame. That is the same fact that forces
the diagnostic bus to be FD in the first place — on classic CAN these responses would
*require* a segmentation layer, and building one is not a skill this event is
testing.

### 1.2 — Find the routines

The interesting service is `RoutineControl` (`0x31`). Routine identifiers are 16-bit,
so sweeping all 65,536 would be a scripted grind rather than a puzzle — the three
that exist are a **contiguous, plausible block**, so finding one makes the others
obvious:

```
0x0201    the pivot
0x0202    "enable diagnostic bridging"     <- see Challenge 2
0x0203    "self-test"                      <- see Challenge 2
```

An unknown identifier returns `requestOutOfRange`, which is what a real ECU does.

### 1.3 — Run the pivot

```sh
python3 tools/ttos-ctf-tool.py pivot --dir cw
```

```
tester → 0x7E0   31 01 02 01 01
car    → 0x7E8   71 01 02 01  "1D8YZGBT"
                 └─ positive  └─ routineStatusRecord = your C1 code
```

**The car rotates in place** — left wheel forward, right wheel reverse, 102 steps
each at 75 rpm, about 45°. Watch it. If the car does not move but you still get a
code, something is wrong with the drivetrain, not the challenge; see
*Troubleshooting*.

Behind that single request the Pi sends three frames on the internal bus:

```
0x115  [01]                             energize the 12 V rail
0x111  00 00 00 66 01 4B <nonce> <crc>  left wheel  102 steps, dir 1, 75 rpm
0x113  00 00 00 66 02 4B <nonce> <crc>  right wheel 102 steps, dir 2, 75 rpm
```

The rail command comes first because the stepper drivers are dead without 12 V and
the BMS boots with the rail off. Opposite directions are what make it a *pivot*
rather than a translation — remember that, it is the whole basis of Challenge 2.

### 1.4 — Redeem

The routine's response carries the flag in submission form — `FLAG{1D8YZGBT}`, 14
bytes, which is another thing that does not fit in a classic frame and rides fine in
an FD one. The two flags that come off the *drive* bus cannot be wrapped at source
(8 bytes is the whole payload there), so the Pi re-announces those on the diagnostic
bus instead; see 2.6 and 3.7.

Paste `FLAG{1D8YZGBT}` into the panel — the bare code works too. The **DIAG bus tab** appears — you can now watch
the diagnostic bus you are already tapping. That is deliberately a modest reward:
you get a nicer view of what you already have.

---

## 2. Challenge 2 — Sessions, and the door that is not the door

> *"The obvious door is locked. The unobvious one is standing open for five seconds."*

**What the contestant is learning:** diagnostic sessions as an access-control
boundary, and that the interesting attack surface is usually a maintenance feature
rather than the thing labelled as the entrance.

### 2.1 — Hit the session wall

```
tester → 0x7E0   22 F1 8C                 read ECU serial
car    → 0x7E8   7F 22 7F                 negative: serviceNotSupportedInActiveSession
```

**The NRC names its own solution.** `0x7F` means "not in *this* session", so change
session:

```
tester → 0x7E0   10 03                    extended diagnostic session
car    → 0x7E8   50 03 00 32 01 F4
tester → 0x7E0   22 F1 8C
car    → 0x7E8   62 F1 8C  "TT-ECU-02-B4CC88BE"
```

Keep that serial. Challenge 3 needs it, and this is the only way to get it.

The session times out after 5 s of silence unless you send `TesterPresent` (`3E 00`)
— standard S3 behaviour, and the tool handles it for you.

### 2.2 — Try the obvious door

```
tester → 0x7E0   31 01 02 02              "enable diagnostic bridging"
car    → 0x7E8   7F 31 33                 securityAccessDenied
```

It is named exactly like the thing you want. **It never opens** — not in the default
session, not in the extended session, not ever. It is a decoy, and it is doing real
teaching work: it is the routine you would pick if you were reading the names rather
than reasoning about behaviour.

### 2.3 — Find the door that is not a door

```
tester → 0x7E0   31 01 02 03              "self-test"
car    → 0x7E8   71 01 02 03 13 88
                                └─ 5000 ms
```

A self-test needs to command the actuators, so it opens an **inbound path from the
diagnostic bus to the drive bus for five seconds**. Nothing about it is labelled as
bridging. This is the shape of a genuine finding: the dangerous capability is a side
effect of a maintenance feature.

The panel's bridging tell flickers while the window is open. The allowlist is
`0x111` and `0x113` only — motor commands. Notably **not** `0x115`, the BMS power
command: a contestant able to cut the 12 V rail from the diagnostic tap could stop a
car mid-challenge, including a car that is not theirs from across the room.

### 2.4 — Build a corpus

You need frames to inject, and you cannot sniff them: the gateway does not carry
drive traffic outbound. The sanctioned source is a snapshot identifier:

```sh
python3 tools/ttos-ctf-tool.py snapshot
```

```
tester → 0x7E0   22 F1 A0
car    → 0x7E8   62 F1 A0  01 11 <8 bytes>  01 13 <8 bytes>
```

The last commanded frame for each wheel, **protection bytes intact**, self-describing
so you do not have to guess which record is which wheel. Readable in the default
session on purpose — C2's difficulty is the window and the composition, and gating
the corpus too would be a second lock on the same door.

Run the pivot **clockwise**, snapshot it, then **counter-clockwise**, and snapshot
again. Now you have four frames: each wheel in each direction.

### 2.5 — Compose

Every frame you hold is from a pivot, so within any single capture the wheels are
opposed. But you have both directions, so take:

```
left wheel  from the clockwise capture          dir = 0x01
right wheel from the counter-clockwise capture  dir = 0x01
```

**Both wheels, same direction.** Each frame is individually authentic — correct CRC,
never modified — but the *pair* is a command the car has never issued. That is the
composition step, and it is the point of the challenge: replay is not enough,
recombination is.

### 2.6 — Open the window and inject

```sh
python3 tools/ttos-ctf-tool.py walk      # does 2.1 through 2.6 automatically
```

Or by hand: fire `31 01 02 03`, then transmit your two composed frames on `0x111`
and `0x113` repeatedly, roughly every 120 ms, for the five seconds you have.

**The car lurches sideways.** It is translating, not pivoting.

The BMS is watching the drive bus it already lives on. Both wheels commanded the same
direction inside 250 ms is a signature no legitimate interface produces, and it emits:

```
0x7D1   "2FQYWXDM"        <- from the BMS, on the DRIVE bus: 8 bare characters,
                             because 8 bytes is the entire payload of a classic
                             CAN frame and "FLAG{...}" is 14
0x7D5   "FLAG{2FQYWXDM}"  <- the same code re-announced by the Pi on the DIAG bus
                             as an FD frame, which has room to say what it is
```

Both repeat at 2 Hz while the condition holds, rather than firing once, so that a
team who solved it without a capture running can simply do it again.

You are tapped on DIAG, so you will see both. Submit the wrapped one; paste either
into the panel. The **DRIVE bus tab** appears, and the panel now names the
telematics interface outright — which is your entrance to Challenge 3.

---

## 3. Challenge 3 — Wireless takeover

> *"Stop borrowing the car's own messages. Write your own."*

**What the contestant is learning:** the actual shape of every headline vehicle
compromise of the last decade — a network-facing service, credentials derived from
data the vehicle will hand you if you ask, and message protection that turns out to
be a checksum rather than a signature.

### 3.1 — Find the service

Two routes, deliberately, because a challenge with a single findable entrance fails
completely for a team that misses it:

```
tester → 0x7E0   22 F1 A1
car    → 0x7E8   62 F1 A1  "192.168.244.1:29537"
```

…or the panel names it once C2 is redeemed.

It listens **on the WiFi AP address only**. It is not reachable over Ethernet — that
would put an authenticated path to the drive bus on the wired network too.

### 3.2 — Derive the key

```
key = SHA-256( VIN : ECU_serial : fleet_salt )   first 16 hex characters
```

Every input is obtainable:

- **VIN** — Challenge 1.
- **ECU serial** — Challenge 2, and it *required* the session skill, not just the flag.
- **Fleet salt** — **it is in the panel's JavaScript**, served to any browser that
  loads the locked page. View source and search for `deriveServiceKey`.

**That is the vulnerability, and it is a real one.** Authentication logic shipped to
the client is among the most common findings in connected-vehicle work — companion
apps and in-car browsers routinely contain the algorithm protecting the thing they
talk to. Shipping it here makes the challenge about *recognising* that pattern rather
than guessing at separators and truncation.

```sh
python3 tools/ttos-ctf-tool.py walk --salt <fleet salt>
# prints the derived key
```

### 3.3 — Authenticate

```
$ nc 192.168.244.1 29537
TTOS-TELEMATICS 1.0
AUTH <key> to begin. Commands: SEND <id>#<hex>, SUB, UNSUB, PING, QUIT
NOTE: every command is acknowledged -- READ EACH RESPONSE before sending the
next, or your connection may be reset with commands still unprocessed.
READY

AUTH 7d4e1f...        → OK authenticated
SUB                   → OK subscribed        (raw drive-bus frames stream to you)
```

**Read every response.** The banner says so for a reason: a client that writes
faster than it reads gets its connection reset with commands still unprocessed, and
that looks exactly like your forgery being rejected.

Five failed authentications in 30 s throttles your source IP for 30 s. A wrong-but-
well-formed key and a malformed key give *different* messages — malformed tells you
so, because failing to notice you pasted 15 characters is not the skill under test —
but a wrong key leaks nothing about how wrong it was.

### 3.4 — Discover that replay is not enough

You are on the internal bus now. Replay a captured frame and the car moves in a fixed
arc at a fixed speed, because that is what the captured frame says. To *drive* it you
need commands the car has never sent — a different step count, a different rpm — and
the moment you change a byte, the protection field is wrong and the motors ignore it.

Silently. The relay answers `OK queued` either way. That uniformity is deliberate:
answering "bad CRC" would be a free oracle, letting you sweep the protection byte and
read the reply instead of recovering the key. **The only feedback is whether the car
moved.**
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

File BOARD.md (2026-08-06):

# TTOS CTF — board copy

Contestant-facing. Safe to print, project, or post. Nothing here reveals a solution.

The three are strictly sequential — each one's output is an input to the next — so
the board reads top to bottom.

---

## Category: **TINYTREK — a car that would rather you didn't**

Eight cars. Each one is a real vehicle network: two CAN buses, three microcontrollers,
a battery manager, and an operator panel that starts out locked. You get a diagnostic
port and the car's WiFi. Everything else you take.

Each challenge ends with a flag of the form `FLAG{XXXXXXXX}`. Paste it into the
car's panel at `http://192.168.244.1` and the panel unlocks more of itself; submit
it to the scoreboard for the points.

Some of the car's internal buses can only carry the eight characters without the
`FLAG{ }` around them — they are eight-byte buses and the wrapper does not fit. If
that is how you found it, that is a correct answer. The panel takes either form and
will show you the full flag to submit.

---

### Challenge 1 — **Do the Diag Dance**

The port under the dash isn't a fault-code reader. It's a live command interface, and
on this car nobody thought to guard it. Introduce yourself properly, ask the car what
it is, and then ask what it can *do* — one of the things it can do makes the wheels
turn. Nothing in this challenge is defended. The whole difficulty is knowing what to
say, in what order, and noticing that the car won't move at all until you've turned
something on first.
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

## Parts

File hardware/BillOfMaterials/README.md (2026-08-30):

# Bill of Materials

Everything you need to source to build one Tiny Trek, split across one overview
list and three per-board component lists.

The **CSV files are the source of truth.** [`BOM.xlsx`](BOM.xlsx) is the same data
in one workbook (one sheet per CSV) for people who would rather work in a
spreadsheet — if the two ever disagree, trust the CSVs.

## The files

| File | What it covers |
|---|---|
| [BOM-Overview.csv](BOM-Overview.csv) | The whole-vehicle list: printed parts, sourced parts (Pi, motors, wheels, battery), wiring, fasteners, and recommended tools. Start here. |
| [BOM-MotorControlBoard.csv](BOM-MotorControlBoard.csv) | Components for one Motor Control Board. **You need two per car.** |
| [BOM-PowerDistroBoard.csv](BOM-PowerDistroBoard.csv) | Components for the Power Distribution Board. One per car. |
| [BOM-UltrasonicSensorBoard.csv](BOM-UltrasonicSensorBoard.csv) | Components for the Ultrasonic Sensor Board. Optional — one per car if you fit it. |

The per-board lists correspond to the fabrication files in
[`../BoardFiles/`](../BoardFiles/) and the schematics in
[`../SchematicsAndWiring/`](../SchematicsAndWiring/).

## How to read a per-board list

- **Reference Designators** match the silkscreen on the board and the schematic.
  Designators in parentheses — e.g. `(A1)`, `(JP1)` — are the header sockets that
  the module named above plugs into, not parts with their own silkscreen mark.
- **Board** (the first row, no designator) is the bare PCB itself. Order it from
  JLCPCB or any fab house using the Gerbers in [`../BoardFiles/`](../BoardFiles/).
- Where a **Digikey** or **Mouser** part number is given, either distributor
  carries an equivalent; the generic 0805 passives (marked "Generic") are
  whatever you have in your parts bin at the listed value.

## Notes

- **Optional parts** are marked `OPTIONAL` in the overview. The camera, the
  ultrasonic sensor board, the CAN-debug snap connectors, and the ferrule/crimp
  tooling can all be skipped for a first build.
- **Quantities** in the overview assume one complete car. The overview already
  accounts for two Motor Control Boards.
- **Amazon links are affiliate links.** Any equivalent part works; nothing here
  requires buying from a specific vendor.

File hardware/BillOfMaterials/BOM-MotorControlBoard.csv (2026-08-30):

MOTOR CONTROL BOARD |  | x2 per car
Reference Designators | Quantity | Description | Package | Value | Manufacturer | Manufacturer Part Number | Vendor | URL | Digikey Part Number | Mouser Part Number
 | 1 | Board | Board |  | JLC/Custom
A1 | 1 | QT Py SAMD21 Dev Board with STEMMA QT (Adafruit) |  |  | Adafruit | 4600 | Adafruit | http://adafru.it/4600
A2 | 1 | CAN Bus BFF Add-on for QT-PY (Adafruit) |  |  | Adafruit | 5877 | Adafruit | http://adafru.it/5877
A3 | 1 | A4988 Stepper Motor Driver Carrier (Pololu) |  |  | Pololu | 2128 | Pololu | http://adafru.it/2128
C1 | 1 | 100 uF Electrolytic Capacitor | CAPPRD350W60D800H1150 | 100uF 35V Electrolytic Radial | Panasonic | EEU-FC1V101 | Digikey/Mouser |  | P10294-ND | 667-EEU-FC1V101
J1 | 1 | 1X3-TERM_BLOCK | PHOENIX_1751251 |  | Phoenix Contact | 1751251 | Amazon/Any | https://amzn.to/3UfWruj
J2, J4 | 2 | 1X2_TERM_BLOCK | PHOENIX_1751248 |  | Phoenix Contact | 1751248 | Amazon/Any | https://amzn.to/4hUBsY3
J3 | 1 | 1X4_TERM_BLOCK | PHOENIX_1751264 | Term BLK 4POS Side Ent 3.5MM PCB | On Shore Technology inc | OSTTE040104 | Digikey/Mouser |  | ED2742-ND
JP1 | 1 | JST Pigtail |  |  | Adafruit | 4336 | Adafruit | http://adafru.it/4336
(A1), (A2) | 4 | female Header 1x7 |  |  | Samtec inc | SSA-107-S-T | Digikey |  | 612-SSA-107-S-T-ND
(A3) | 2 | Female Header 1x8 |  |  | Samtec inc | SSA-108-S-T | Digikey |  | 612-SSA-108-S-T-ND

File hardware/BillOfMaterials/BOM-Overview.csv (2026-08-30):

TINY TREK BOM - OVERVIEW
Qty | Printed Parts | Notes | URL
1 | Car Chassis |  | See Github Repo - https://github.com/sixvolts/TinyTrek/tree/main/hardware/3DModels/TinyTrekV1pt5.stl
1 | Battery Holder | m12_flashlight_lower_body | https://www.printables.com/model/96306-milwaukee-m12-flashlight-with-adjustable-head
1 | Battery Extension |  | See Github Repo - https://github.com/sixvolts/TinyTrek/tree/main/hardware/3DModels/battExtender.stl
1 | Camera Board Bracket | OPTIONAL | See Github Repo - https://github.com/sixvolts/TinyTrek/tree/main/hardware/3DModels/camBracket.stl
1 | Snap Connector Bracket | OPTIONAL | See Github Repo - https://github.com/sixvolts/TinyTrek/tree/main/hardware/3DModels/snapConnectorBracket.stl
Qty | Board Assemblies | Notes | URL
2 | Motor Control Boards |  | See Tab
1 | Power Distribution Board |  | See Tab
1 | Ultrasonic Sensor Board | OPTIONAL | See Tab
Qty | Sourced Parts | Notes | Vendor | URL
1 | Raspberry Pi 4 2GB |  | Any | https://amzn.to/4hxqbwt
1 | Waveshare 2 CAN-FD Hat |  | Amazon/Any | https://amzn.to/45wxLQJ
1 | DF Robot Camera Board | OPTIONAL | DF Robot | https://www.dfrobot.com/product-2899.html
2 | NEMA 14 Motors |  | Pololu | https://www.pololu.com/product/1208
1 | Set of Pololu Wheels |  | Pololu | https://www.pololu.com/product/1423
2 | Set of Pololu Wheel Adapters |  | Pololu | https://www.pololu.com/product/1998
1 | Polulu Ball Caster |  | Pololu | https://www.pololu.com/product/2692
1 | A2-class MicroSD Card (32 or 64GB) |  | Amazon | https://amzn.to/4wpFISF
1 | M12-compatible Battery |  | Amazon | https://amzn.to/45vU49i
Qty | Wiring | Notes | Vendor | URL
1 | 20AWG Wire in Red, Black, Blue, Yellow, Green |  |  | https://amzn.to/4hyI51X
1 | Pre-twisted Yellow/Green CAN bus wire | OPTIONAL |  | https://amzn.to/45vBL46
bulk | 22AWG Ferules | OPTIONAL |  | https://amzn.to/4x4SIhW
bulk | 20AWG Ferrules | OPTIONAL |  | https://amzn.to/3RXuozg
bulk | 26AWG Ferules (motor wires) |  |  | https://amzn.to/3RU7hpj
2 | 6.3mm Male Spade connectors |  |  | https://amzn.to/4g9kO47
1 | Power Switch |  |  | https://amzn.to/4bLJb6N
1 | Green Snap Connectors (CAN Debug) | OPTIONAL |  | https://amzn.to/3UBK6kd
1 | Yellow Snap Connectors (CAN Debug) | OPTIONAL |  | https://amzn.to/4ww65qc
Qty | Fasteners | Notes | Vendor | URL
4 | m2.5 hex nuts |  |  | https://amzn.to/4qkaVFv
4 | m2.5 screws 6mm |  |  | https://amzn.to/4hvW3Sa
4 | m2.5 standoff screws 15mm + 6mm |  |  | https://amzn.to/4g8AOU4
35 | m3 x 6mm screws |  |  | https://amzn.to/45uvhT2
14 | m3 x 8mm screws |  |  | https://amzn.to/4qtf5ej
3 | m3 x 10mm screws |  |  | https://amzn.to/3TQgqzN
3 | m3 x 12mm screws |  |  | https://amzn.to/45tFwa8
10 | M3 x 16mm standoffs |  |  | https://amzn.to/4x82v6W
6 | M3 x 8mm standoffs | OPTIONAL |  | https://amzn.to/4hMrLL1
1 | M2.5 Standoff Kit | OPTIONAL |  | https://amzn.to/4x1SQP9
1 | M3 Screw Kit | OPTIONAL |  | https://amzn.to/4xO2Xap
1 | CA Glue |  |  | https://amzn.to/4iwZQyW
bulk | 4" zipties |  |  | https://amzn.to/4gFGFRa
Qty | Tools (Recommended) | Notes | Vendor | URL
1 | Soldering Iron - Pinecil |  |  | https://amzn.to/4qmH0wy
1 | Solder - MG 63/37 |  |  | https://amzn.to/4gjxhT6
1 | flush cutters |  |  | https://amzn.to/4gh0IoE
1 | tweezers |  |  | https://amzn.to/4hD1fUo
1 | Ferrule Crimper | OPTIONAL |  | https://amzn.to/4qnEbLN
1 | spade connector crimper | OPTIONAL |  | https://amzn.to/3UlB2jG
1 | wire strippers |  |  | https://amzn.to/4zOb4Wi
1 | Hot Glue gun | OPTIONAL |  | https://amzn.to/4g9WNtS
1 | Hot glue sticks | OPTIONAL |  | https://amzn.to/4gwMVdL
* Amazon links are affiliate links.

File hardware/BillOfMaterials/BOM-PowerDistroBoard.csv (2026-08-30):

POWER DISTRIBUTION BOARD - BOM
Reference Designators | Qty | Description | Package | Value/Notes | Manufacturer | Manufacturer Part Number | Vendor | Source | Digikey Part | Mouser Part
 | 1 | Board |  |  | Custom/JLC
A1 | 1 | Feather RP2040 with Can Bus |  |  | Adafruit | 5724 | Adafruit | http://adafru.it/5724
C1 | 1 | 100 uF Electrolytic Capacitor | CAPPRD350W60D800H1150 | 100uF 35V Electrolytic Radial | Panasonic | EEU-FC1V101 | Digikey |  | P10294-ND | 667-EEU-FC1V101
C2 | 1 | Ceramic Capicitor | 1206 | 10uF 25V x5R | Samsung Electro-Mechanics America | CL31A106MAHNNNE | Digikey |  | 1276-1181-1-ND | 80-CL31A106MAHNNNE
D1 | 1 | Diode | 1N4148_DIODE | 100V Io/200mA | OnSemi | 1N4148 | Mouser |  | 1N4148FS-ND | 512-1N4148
D2 | 1 | Green LED | 0805 | Generic (Panasonic Default) | Generic
J1, J2, J5 | 3 | 1X2_TERM_BLOCK | PHOENIX_1751248 | Screw Terminals | Phoenix Contact | 1751248 | Amazon/Any | https://amzn.to/4hUBsY3
J3, J4 | 2 | 1X3-TERM_BLOCK | PHOENIX_1751251 | Screw Terminals | Phoenix Contact | 1751251 | Amazon/Any | https://amzn.to/3UfWruj
K1 | 1 | RELAY-JQC-3F-T73 | JQC-3FT73 | Relay for 12V to Motors | Generic |  | Amazon | https://amzn.to/4i9zaUK
Q1 | 1 | NFET-BS170 | TO-92 | Basic N-FET for Relay | OnSemi | BS170 | Mouser |  | BS170-ND | 512-BS170
R1 | 1 | Resistor | 0805 | 10K | Generic (Panasonic Default)
R2 | 1 | Resistor | 0805 | 120K 0.5% 1/4W | Panasonic Electronic Components | ERJ-PB6D1203V | Digikey |  | P21255CT-ND
R3 | 1 | Resistor | 0805 | 40.2K 0.5% 1/4W | Panasonic Electronic Components | ERJ-PB6D4022V | Digikey |  | P21201CT-ND
R4 | 1 | Resistor | 0805 | 470 | Generic (Panasonic Default)
VR1 | 1 | Voltage Regulator * | MURATA-78S | Murata 7805 Replacement | Murata | OKI-78SR-5/1.5-W36H-C | Mouser |  | 811-2692-ND | 580-OKI78SR51.5W36HC
(A1) | 1 | Conn rcpt 12POS 0.1 TIN PCB |  |  | Samtec inc | SSA-112-S-T | Digikey |  | 612-SSA-112-S-T-ND
(A1) | 1 | Conn Rcpt 16 POS 0.1 TIN PCB |  |  | Samtec inc | SSA-116-S-T | Digikey |  | 612-SSA-116-S-T-ND

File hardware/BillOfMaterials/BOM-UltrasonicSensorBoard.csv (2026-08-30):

ULTRASONIC SENSOR BOARD
Reference Designators | Quantity | Description | Package | Manufacturer | Manufacturer Part Number | Vendor | URL | Digikey Part
 | 1 | Board | Board | JLC/Custom
A1 | 1 | QT Py SAMD21 Dev Board with STEMMA QT (Adafruit) | QTPY-TH-ADAFRUIT | Adafruit | 4600 | Adafruit | http://adafru.it/4600
A2 | 1 | CAN Bus BFF Add-on for QT-PY (Adafruit) | CAN-BUS_BFF-TH-ADAFRUIT | Adafruit | 5877 | Adafruit | http://adafru.it/5877
J1, J2 | 2 | 1X2_TERM_BLOCK | PHOENIX_1751248 | Phoenix Contact | 1751248 | Amazon | https://amzn.to/4hUBsY3
JP1 | 1 | US-100 Ultrasonic Distance Sensor |  | Adafruit | 4019 | Adafruit | http://adafru.it/4019
JP2 | 1 | JST Pigtail |  | Adafruit | 4336 | Adafruit | http://adafru.it/4336
(A1), (A2) | 4 | female Header 1x7 |  | Samtec inc | SSA-107-S-T | Digikey |  | 612-SSA-107-S-T-ND
(JP1) | 1 | female Header 1x5 |  | Samtec inc | SSA-105-S-T | Digikey |  | 612-SSA-105-S-T-ND

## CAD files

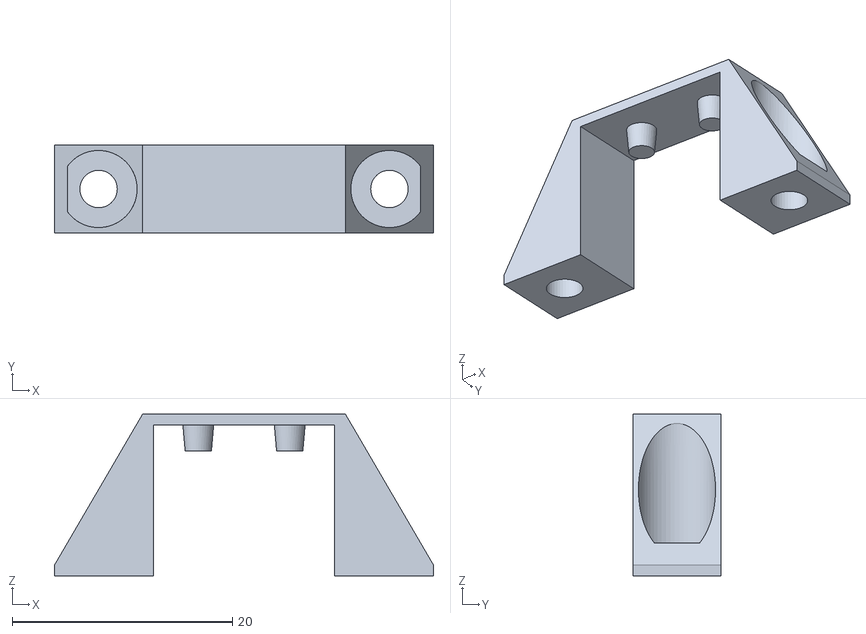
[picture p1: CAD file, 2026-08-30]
hardware/3DModels/snapConnectorBracket.stl
34.4 x 8.00 x 14.7

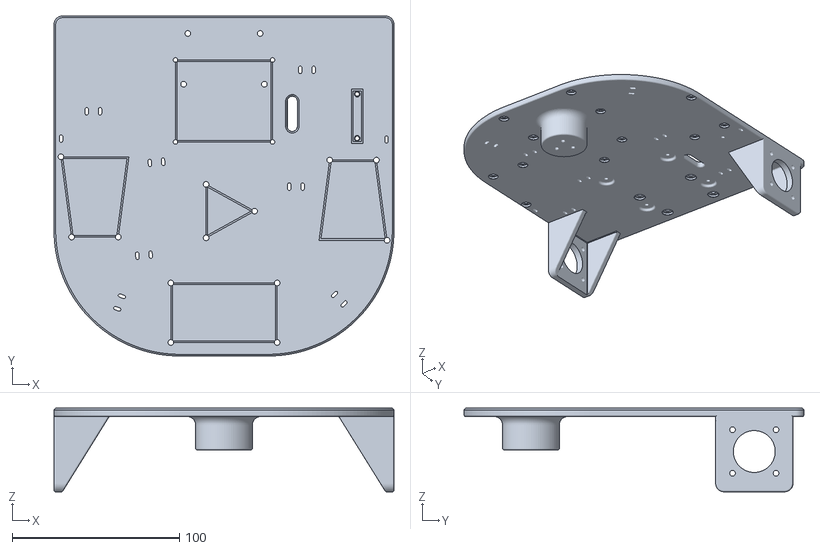
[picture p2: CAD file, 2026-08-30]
hardware/3DModels/TinyTrekV1pt5.stl
203.2 x 203.2 x 50.0

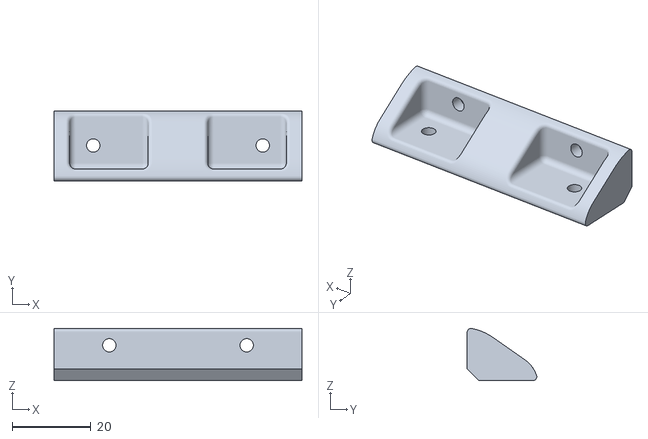
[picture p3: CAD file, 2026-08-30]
hardware/3DModels/camBracket.stl
63.2 x 17.7 x 13.3

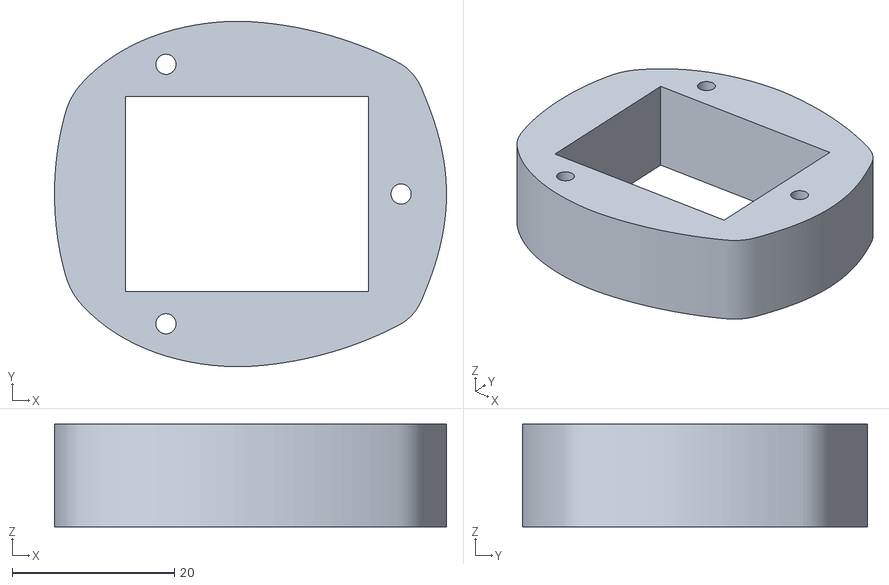
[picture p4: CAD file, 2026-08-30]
hardware/3DModels/battExtender.stl
48.3 x 42.6 x 12.7

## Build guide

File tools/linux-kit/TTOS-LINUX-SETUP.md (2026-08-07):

# TTOS CTF — Linux operator setup

**For:** a Claude Code session on a Linux laptop that needs to drive a TTOS CTF car
with a **PEAK PCAN-USB (Pro) FD** adapter.

**Why Linux:** the same PEAK adapter works two ways. On macOS it goes through
MacCAN/libPCBUSB, which on this hardware transmitted fine but silently dropped every
CAN FD *reply* — commands landed, answers vanished. On Linux the adapter binds the
in-kernel `peak_usb` driver via **socketcan**, which is the exact path the bench host
already uses successfully. No MacCAN, no libPCBUSB, no FD-receive problem.

This kit is three files, meant to sit in one folder:

```
ttos-can-up.sh        # brings the adapter up and finds the diagnostic bus
ttos-ctf-tool.py      # the CTF tool (pure Python stdlib — nothing to pip install)
TTOS-LINUX-SETUP.md   # this file
```

---

## TL;DR

```sh
cd <this folder>
./ttos-can-up.sh
```

It re-runs itself under `sudo`, brings up every CAN interface at 500 k/1 M CAN FD,
identifies which one is the car's diagnostic bus, and prints the exact `walk` command
to run. If it prints a `READY` block, you are done — copy the command it gives you.

---

## What the adapter and the bus are

- **Adapter:** PEAK PCAN-USB FD, possibly the dual-channel **Pro FD**. A dual adapter
  shows up as **two** interfaces (`can0` and `can1`); a single-channel one as a single
  interface. The script handles either — you do not need to know which is which.
- **Bus:** the car's **diagnostic** tap. **500 kbit** arbitration, **1 Mbit** data,
  **CAN FD**, ISO. FD is not optional: every reply in this game (VIN, the pivot flag,
  the snapshot) is longer than 8 bytes, so a classic-only setup would send fine and
  never receive an answer.
- You plug **one** connector into the car's diagnostic port. On a dual adapter the
  other channel is unused; the script will see it answer nothing and ignore it.

---

## Prerequisites (Claude Code: check and install these)

1. **A recent-ish kernel with `peak_usb`.** It is an in-tree module; nothing to
   install on any mainstream distro from the last decade. Confirm after plugging in:
   ```sh
   dmesg | grep -i peak        # should show the adapter attaching
   ip -o link show type can    # should list can0 (and can1 on a dual adapter)
   ```
2. **python3** — the tool is stdlib-only (raw `AF_CAN` socket). No `python-can`, no
   pip. `apt install python3` if somehow absent.
3. **can-utils** (recommended, not required) for `candump`/`cansend` when hand-debugging:
   ```sh
   sudo apt install can-utils
   ```
4. **Root.** Raw CAN sockets and `ip link` need it. The script re-execs under `sudo`;
   run the tool by hand with `sudo` too.

---

## Manual path (if you would rather not run the script)

```sh
# 1. driver + see the interface
sudo modprobe peak_usb
ip -o link show type can

# 2. bring it up as CAN FD, 500k/1M  (repeat for can1 if the adapter is dual-channel)
#    This is the exact command the bench host uses; let the kernel pick sample points.
sudo ip link set can0 down
sudo ip link set can0 up type can bitrate 500000 dbitrate 1000000 fd on

# 3. which interface is the diagnostic bus?  It answers a VIN; the drive bus does not.
#    (vin sends no motion command — safe to try on each.)
sudo python3 ttos-ctf-tool.py --transport socketcan --iface can0 vin
sudo python3 ttos-ctf-tool.py --transport socketcan --iface can1 vin   # dual adapter only
```

The interface that prints a VIN like `TTKTREK17TC000003` is your diagnostic bus.

---

## Running the game

Replace `can0` with whatever the script (or the VIN test) identified.

```sh
# The whole chain, C1 -> C2 -> C3, with the flags printed at each step:
sudo python3 ttos-ctf-tool.py \
     --transport socketcan --iface can0 \
     --salt dd1b35d820f614e9c94f6a0e4f34cbc3 walk

# Single steps:
sudo python3 ttos-ctf-tool.py --transport socketcan --iface can0 vin
sudo python3 ttos-ctf-tool.py --transport socketcan --iface can0 pivot     # car turns in place
sudo python3 ttos-ctf-tool.py --transport socketcan --iface can0 snapshot
sudo python3 ttos-ctf-tool.py --transport socketcan --iface can0 monitor   # passive listen, ^C to stop
```

`--salt` is a **global** option: it goes **before** the `walk` subcommand, not after.
The fleet salt is `dd1b35d820f614e9c94f6a0e4f34cbc3` (it is not a secret — it also
ships in the panel's page source as `deriveServiceKey`).

Add `--debug` to any command to print every frame in and out.

---

## What "working" looks like

`walk` should reach `full chain OK` and print three flags:

```
FLAG{1D8YZGBT}     (C1, from the pivot routine)
FLAG{2FQYWXDM}     (C2, seen on the bus as the car is caught translating)
FLAG{3CX5E77Z}     (C3, after forging a drive command)
```

(Those are the shared fleet codes. Every car emits the same three.)

---

## Troubleshooting

- **`No CAN interfaces present`** — `peak_usb` did not bind. Re-plug, `sudo modprobe
  peak_usb`, check `dmesg | grep -i peak`. A USB hub or a bad cable is the usual cause.
- **`No interface answered a VIN`** — the request is going out but nothing replies.
  On Linux this is almost never the adapter (it is the proven path). Check, in order:
  the connector is on the **diagnostic** port, CAN-H/CAN-L are not swapped, the car is
  powered, and `ttos-dashboard` is running on it. A **silent** DIAG bus on `candump`
  is normal — it only speaks when spoken to.
- **The car pivots but you still get no VIN** — that was the macOS failure mode
  (transmit works, FD receive dies). It should NOT happen on Linux/socketcan. If it
  does, run `... vin --debug`: an `RX 7E8#...` line means the reply arrived; no `RX`
  line means FD frames are not being delivered, which on Linux would point at a
  genuinely old kernel — try another machine.
- **`Permission denied` / nothing happens** — you forgot `sudo`. Raw CAN needs root.

---

## For the panel (separate from the CAN tool)

The tool above talks to the car over CAN and needs no WiFi. To reach the **panel**
(to paste flags, watch buses), join the car's AP in a browser:

```
SSID   ttos-car-NN         (per car, on the placard)
PSK    TINYTREKCTF         (shared across the fleet)
URL    http://192.168.244.1
Browser: Safari or Firefox — Chrome force-upgrades :80 to HTTPS and the panel looks dead.
```

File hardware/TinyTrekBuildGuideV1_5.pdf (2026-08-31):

# TinyTrek V1.5 Build Guide

Proto Squirrel | SixVolts | capt redbeard
| August 2026

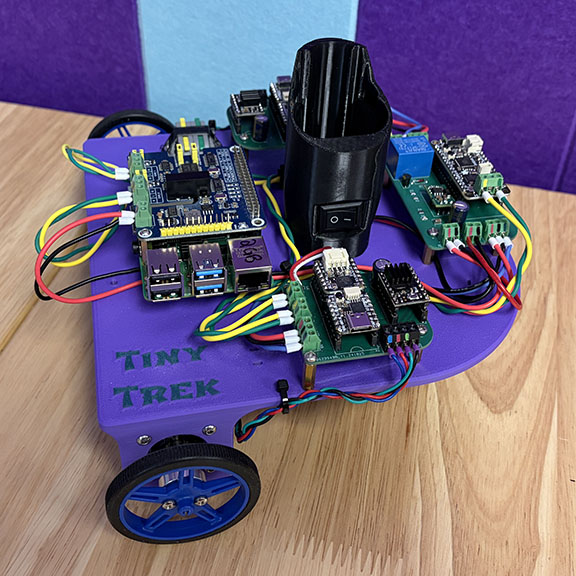
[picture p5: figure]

## 3D Print

There are three parts that must be printed to make the main Tiny Trek chassis and few optional parts. The print settings specified below are the settings we used to print the parts. They may not be the optimal settings for your machine.

Required parts

Chassis

You will need to print the chassis top-down on the build plate. The chassis is 8” x 8”, so you will need a medium sized printer. There is an outline of a Tiny Trek logo that could be filled in for optional multi color printing. Textured build plates, such as PEI, work without issues.

Filament: We recommend using a higher-temp filament like HTPLA or PETG. Both work well in our testing. Something like regular PLA will probably work fine too, but ultimately that’s up to you and how it fits your application.

Print settings:
Nozzle: 0.4mm
Layer Height: 0.2mm
Wall Loops: 3
Top Shell Layers: 5
Bottom Shell Layers: 3
Infill: 20% Cubic
Supports: Not needed

Battery Receptacle

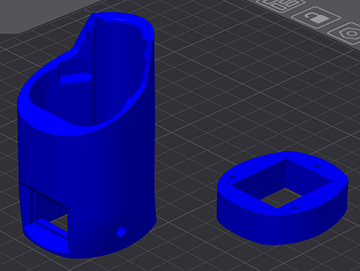
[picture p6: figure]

The other two required pieces are the M12 battery receptacle and the battery receptacle extender. The cavity in the extender provides room for the wiring after installing the switch. We used a model from an external source for the battery holder and added the extender to suit TinyTrek.

Filament: PLA and PETG both work, but given shrinkage and mechanical “slipperiness”, PETG is the superior choice for the battery receptacle. It tends to be easier to get the battery in and out.

Print Settings:
Nozzle: 0.4mm
Layer Height: 0.2mm
Wall Loops: 2
Top Shell Layers: 5
Bottom Shell Layers: 3
Infill: 15% Cubic
Supports: Difficult to remove, cleanup will be necessary whether you use supports or not given the way this particular model was designed.

Optional parts

Camera Bracket

This bracket allows you to mount DFRobot’s ESP32-S3 AI Camera Module in a vertical orientation at the front of the chassis giving a FPV of sorts. The bracket was designed with a chamfer so the print should be oriented in such a way that both ”legs” of the L shape are oriented at a 45 degree angle to the print bed.

Filament: This holds a potentially fragile part in a potentially precarious orientation. Stronger may be better. We used PETG.

Print settings:
Nozzle: 0.4mm
Layer Height: 0.2mm
Wall Loops: 3
Top Shell Layers: 5
Bottom Shell Layers: 3
Infill: 20% Cubic
Supports: Not needed

Snap Connector Bracket

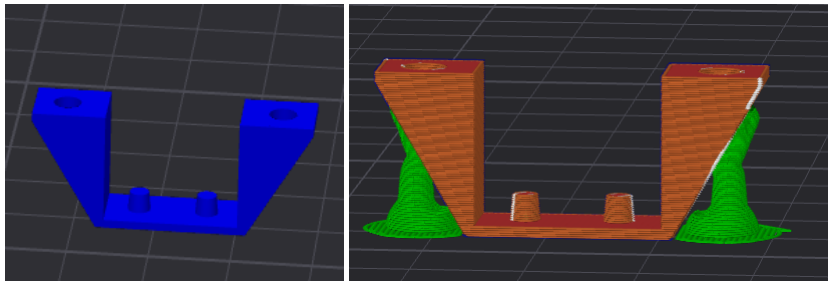
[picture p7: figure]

This bracket allows you to connect a pair of the recommended snap connectors to the chassis to provide a quick-release of an external device to one of the on-board CAN Buses. This bracket was specifically designed to slot into holes in the top of the specified connectors, so it may not work with other brands. Bracket should be printed upside down with the legs and small nubs facing up.

Print settings:
Nozzle: 0.4mm
Layer Height: 0.2mm
Wall Loops: 3
Top Shell Layers: 5
Bottom Shell Layers: 3
Infill: 20% Cubic
Supports: Tree supports are preferred to prevent drooping, but the part is so small that the drooping does not keep it from functioning.

## Assemble the Battery Receptacle

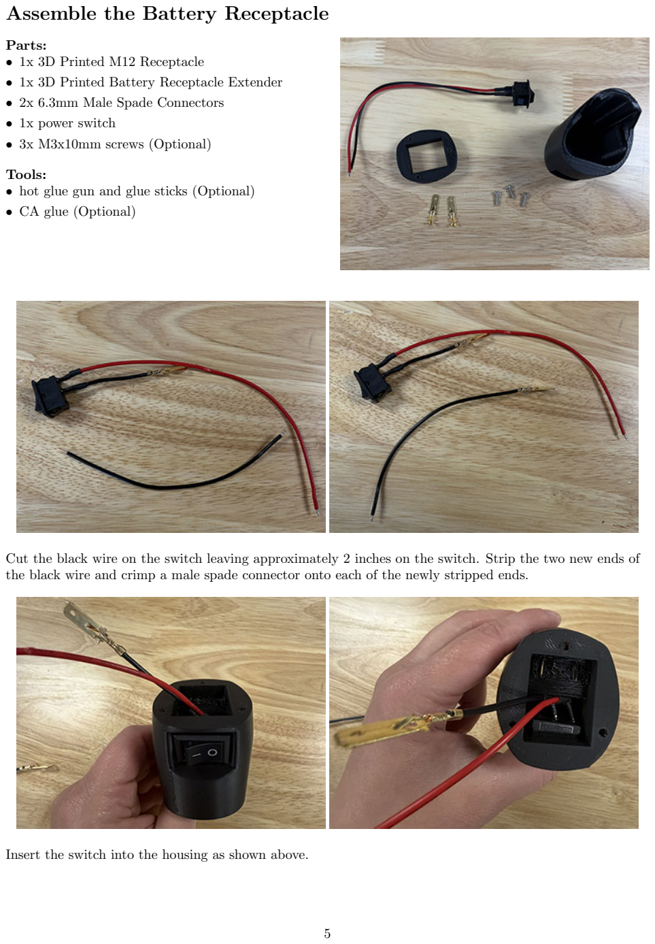
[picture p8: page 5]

Parts:
- 1x 3D Printed M12 Receptacle
- 1x 3D Printed Battery Receptacle Extender
- 2x 6.3mm Male Spade Connectors
- 1x power switch
- 3x M3x10mm screws (Optional)

Tools:
- hot glue gun and glue sticks (Optional)
- CA glue (Optional)

Cut the black wire on the switch leaving approximately 2 inches on the switch. Strip the two new ends of the black wire and crimp a male spade connector onto each of the newly stripped ends.

Insert the switch into the housing as shown above.

Cross the black wire to the other side of the housing and insert the spade connector into the slot on the right. Insert the other black wire with the spade connector into the left slot. The switch should now be on the hot side of the battery. Double check your connection by carefully inserting a battery into the receptacle and measuring the voltage at the wire ends both with the switch off and on. If you read a positive voltage with the battery, your receptacle is wired up properly.

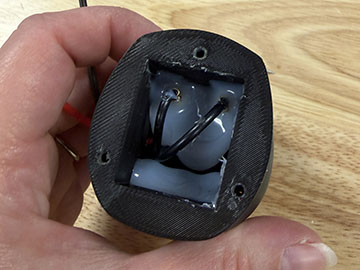
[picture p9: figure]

Optionally, you can reinforce the connection with hot glue to keep the spade connectors in place and add a small amount of strain resistance.

Feed the exposed wire ends through the small hole in the side of the extender and make sure the hole lines up on the left side of the receptacle. Attach the extender to the bottom of the receptacle with either 3 M3x10mm screws going in from the battery opening or by applying CA glue between the two pieces.

## Assemble Custom PCBs

Assemble Power Distribution Board V1.1

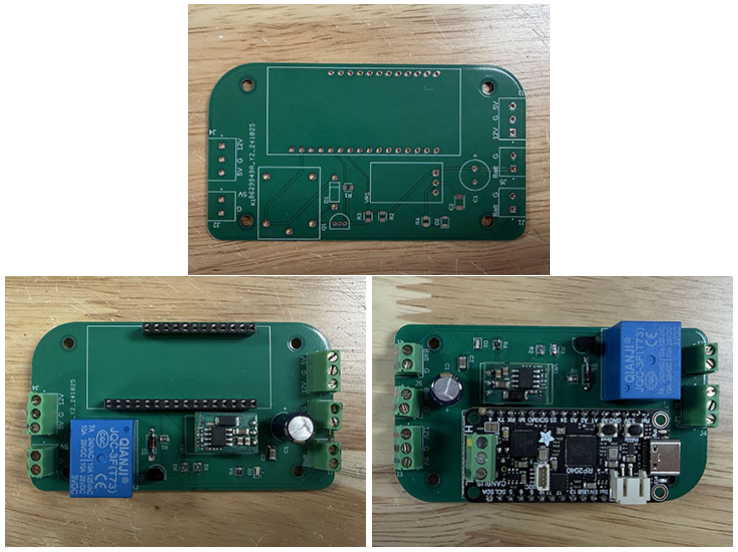
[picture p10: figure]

Assemble the Power Distribution Board as shown above.

A few things of note: There are a handfull of very similar Voltage regulators, but they aren’t identical -check orientation against the proper datasheet. Input Voltage should go in the hole with the square pad for VR1. Headers for the Feather make it much easier to both program the Feather and swap out a misbehaving Feather.

Assemble Motor Controller Boards

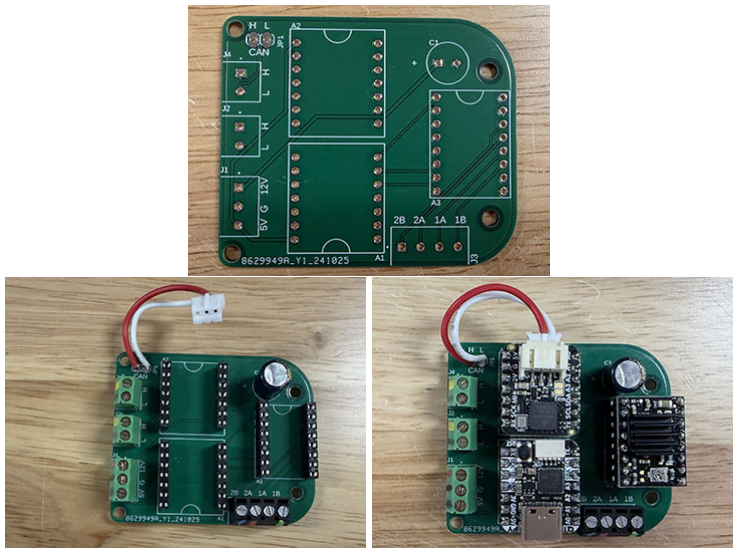
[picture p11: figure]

The two motor controller boards are assembled identically. The difference comes in the code and the way the motor coils are hooked up. Female headers in the board allow easy removal of the daughter boards here as well for programming the QTPY or replacing misbehaving parts.

On the bottom side of the CANBFF there is a series of 4 jumpers. By default, INT, STBY and RST are open and CS is closed [left]. We want all four closed. This can be achieved with a solder blob [right]. I recommend making this modification before soldering headers to the CAN BFF. You will need to make this modification for both motor controllers and for the optional Ultrasonic Sensor module. These jumpers allow the CAN BFF to talk to the QTPY over SPI.

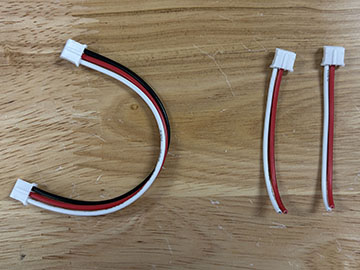
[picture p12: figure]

The JST pigtail is created by cutting the specified cable in half and removing the black wire. The resulting pigtail should have the white wire in the CAN-Low position and the red wire in the CAN-High position. Check the label on the Motor Controller Module board against the labels on the JST jack on the CAN BFF.

OPTIONAL: Assemble the Ultrasonic Sensor Module

CAUTION: We do not currently have any code written for the Ultrasonic Sensor Module, thus it has not been successfully tested. There is also a hardware jumper on the back of the US-100 Ultrasonic Sensor that is used to change the communication mode and may be impossible or at least incredibly difficult to change if you solder the ultrasonic sensor directly to the custom board. You may wish to use a female header there as well.

The Ultrasonic Sensor Module uses the same QTPY and CANBFF setup as the Motor Controller Modules, so the same caveats about the Jumpers on the back of the CANBFF and the CAN pigtail apply here as well.

## Mount Ball Caster

Parts:
- Pololu Ball Caster kit
- 3 x M3x6mm screws

Before assembling the ball caster housing, screw the base to the chassis on the protrusion at the bottom back of the chassis with 3 M3x6mm screws.

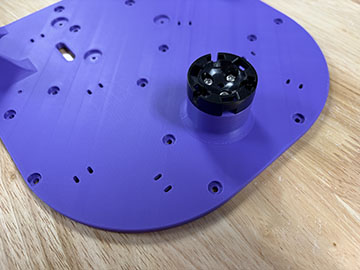
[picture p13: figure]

Assemble the ball caster in place.

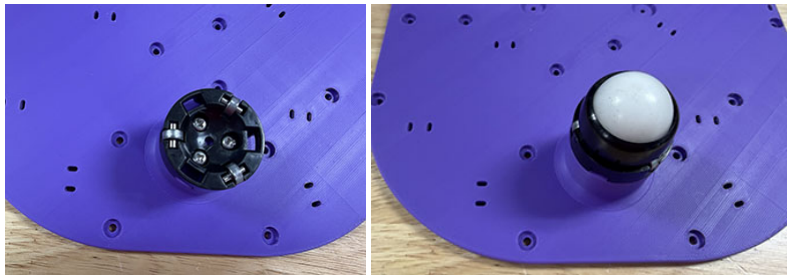
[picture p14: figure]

## Mount Electronics to Chassis

Battery Receptacle

Parts:
- 1 x M12 Receptacle Assembly
- 3 x M3x12mm screws

The battery receptacle assembly can be attached to the chassis on the triangle with 3 M3x12mm screws coming up from the bottom. The power switch will be facing the left side of the chassis, and the wires should be leading toward the rear of the chassis.

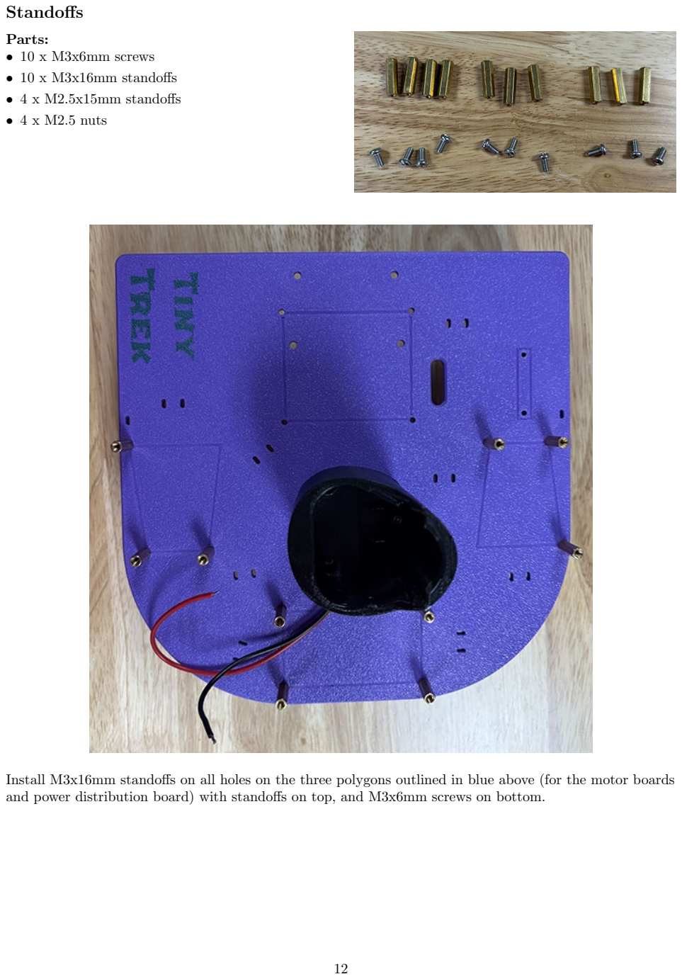
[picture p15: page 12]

Standoffs

Parts:
- 10 x M3x6mm screws
- 10 x M3x16mm standoffs
- 4 x M2.5x15mm standoffs
- 4 x M2.5 nuts

Install M3x16mm standoffs on all holes on the three polygons outlined in blue above (for the motor boards and power distribution board) with standoffs on top, and M3x6mm screws on bottom.

Install M2.5 Standoffs on the 4 holes on the large rectangle for the Raspberry Pi with standoffs on top and nuts on the bottom of the chassis.

Optional Ultrasonic Sensor and/or Camera Board

Parts:
- 4 x M3x6mm screws
- 6 x M3x8mm Standoffs (16mm standoffs are ok,
but not optimal here.)
- 1 x printed Camera Bracket
- 2 x M3x8mm screws

Camera Bracket

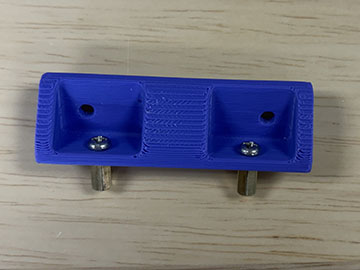
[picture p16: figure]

Install 2 M3x8mm standoffs on the side on the holes closer together. Standoffs on the flat side, M3x6mm screws on the inside of the bracket.

Ultrasonic Sensor Standoffs

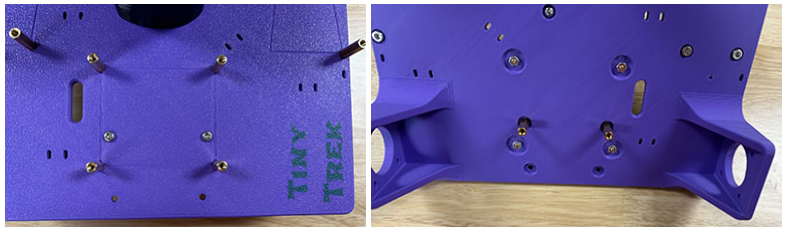
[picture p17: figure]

Install M3x8mm standoffs in the back 2 holes with standoffs on bottom, M3x6mm screws on top.

If using the Camera Bracket, 2 M3x8mm screws go through the Bracket and the Chassis into the standoffs at the front of the chassis.
(If you aren’t using the camera, the front two standoffs install the same way as the back two.)

Motor controller boards

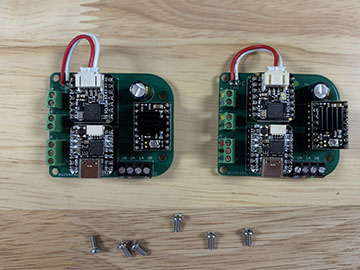
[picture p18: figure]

Parts:
- 2 x Assembled Motor Controller Boards
- 6 x M3x6mm screws

Using 3 M3x6mm screws each, install Motor Controller Boards on the two trapezoids. Note: There will be one unpopulated screw hole on each board. The screw hole is uncomfortably close to the pads for the CAN Bus so I explicitly didn’t include the hole in the chassis to prevent accidentally shorting the CAN Bus with a standoff or screw.

Motors

Parts:
- 2 x Nema 14 stepper Motors
- 8 x M3x8mm screws

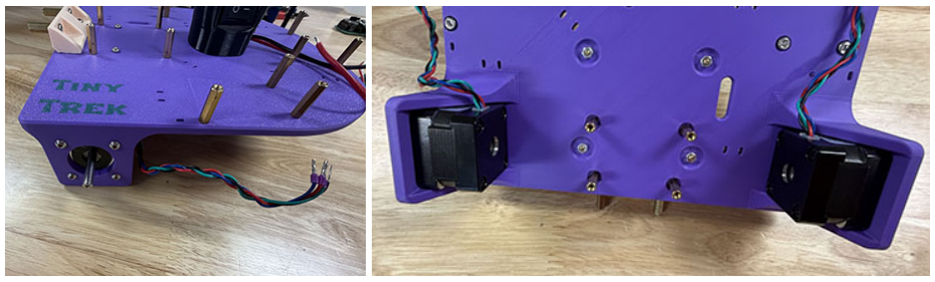
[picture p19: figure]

Using 4 M3x8mm screws each, install motors with the wires pointing towards the back of the chassis.

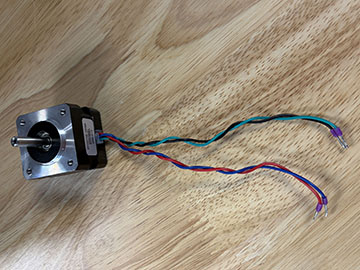
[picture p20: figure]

Optionally, use a drill to twist the two wires from each coil together. (i.e. red/blue and green/black) Cut wires to the appropriate length to reach the black screw terminal.

Power Distribution Board

Parts:
- 1 x Assembled Power Distribution Board
- 4 x M3x6mm screws

Route the wires from the battery receptacle between the standoffs as shown in the above left image. Use 4 M3x6mm screws to install the Power Distribution Board on the small rectangle with the Feather daughter board towards the back of the chassis.

Raspberry Pi and CAN FD Hat

Parts:
- 1 x Raspberry Pi 4B 2GB
- 1 x CAN FD Hat
- 4 x M2.5x6mm screws
- 2 x M2.5x15mm standoffs

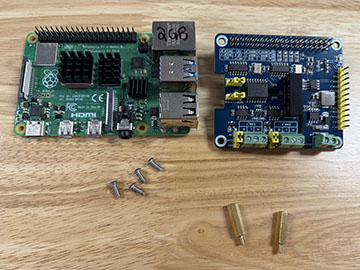
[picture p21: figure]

BEFORE installing the Raspberry Pi, if you are using the Ultrasonic sensor, and/or the camera module, make sure the standoffs for the Ultrasonic Sensor and the Bracket for the Camera are installed. (see Optional Ultrasonic Sensor and/or Camera Board)

Place the Raspberry Pi on the M2.5 standoffs. USB and Ethernet ports face the left side of the chassis. Use M2.5x6mm screws in the 2 holes on either side of the header bank, and M2.5x15mm standoffs in the front 2 holes.

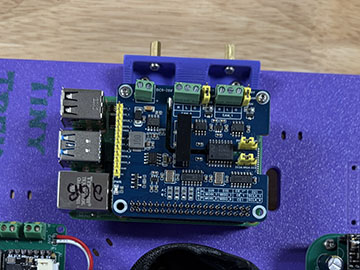
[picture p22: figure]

Install the CAN-FD Hat and screw down the front two holes with 2 more M2.5x6mm screws.

Ultrasonic Sensor Module

Parts:
- 1 x Assembled Ultrasonic Sensor Module
- 4 x M3x6mm screws

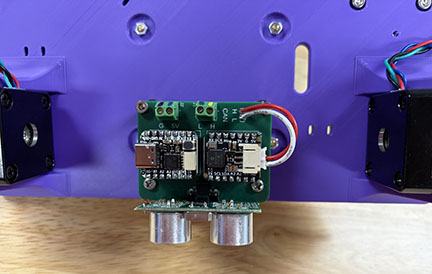
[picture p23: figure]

Install the Ultrasonic Board on the bottom of the chassis with 4 M3x6mm screws

Camera

Parts:
- 1 x ESP32-S3 AI Camera Module
- 2 x M3x6mm screws

The camera board installs on the front of the camera bracket with 2 M3x6mm screws.

## Wiring

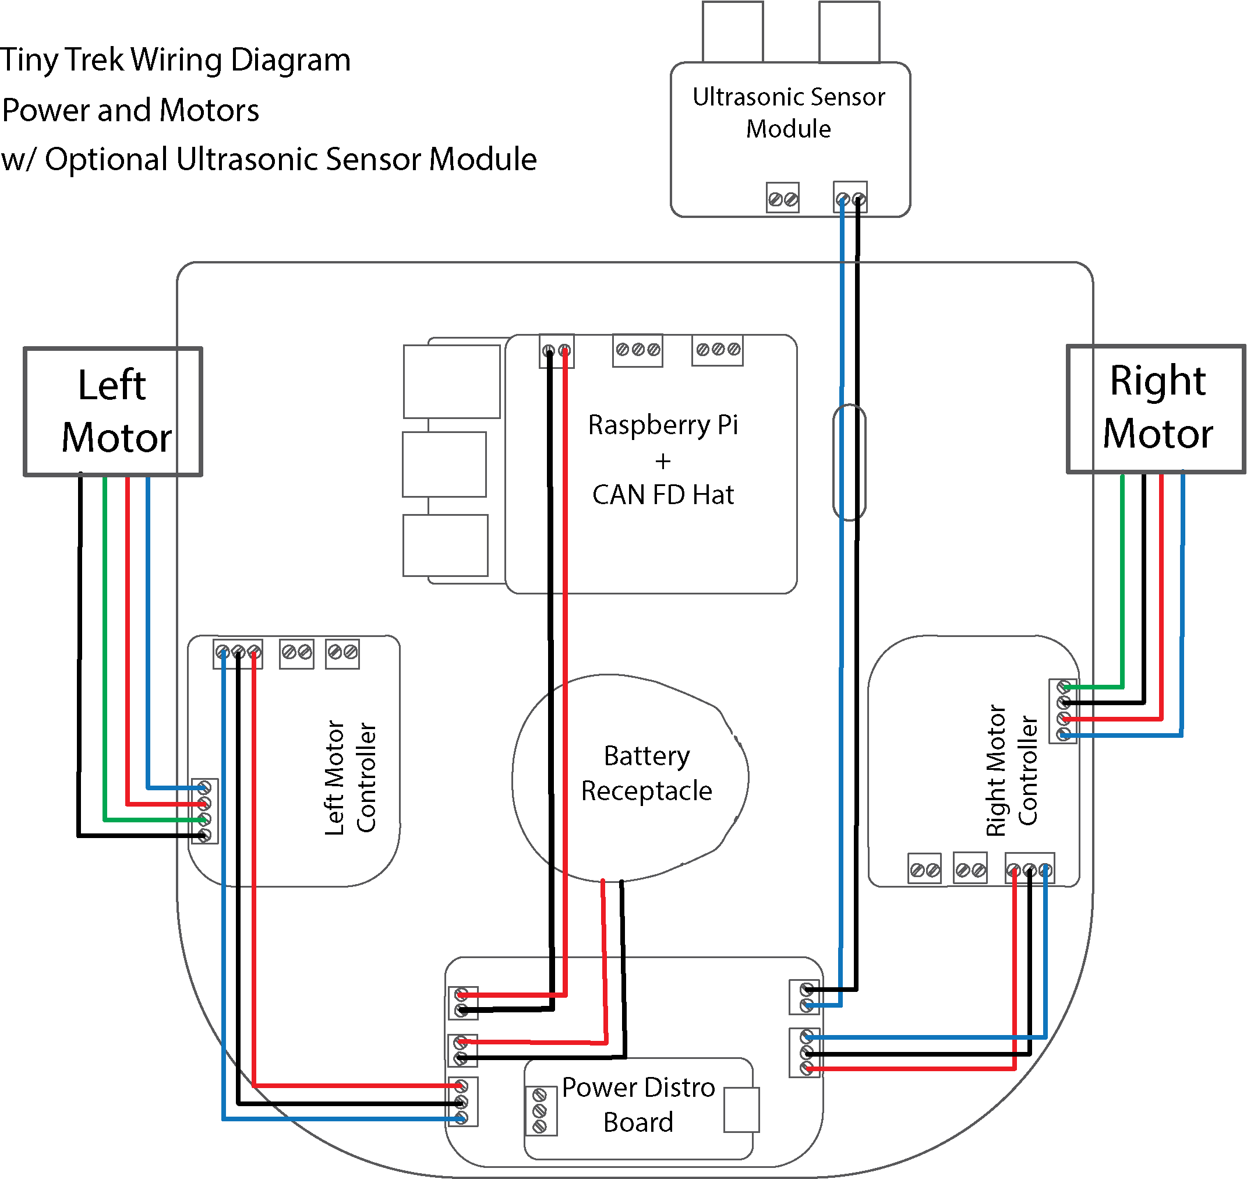
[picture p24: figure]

I used Red wire for 12V and Blue for 5V. Optionally you could add a third color to differentiate between 12V straight from the battery and 12V out of the relay.

Set Motor Current Limit

Before you wire everything up, and before connecting the motors, you will want to set the current limit on the Motor Controller Modules. You will have to connect some of the wiring. Connect the battery to the Power Distribution Board. Connect 5V and Gnd from the Power Distribution Board to the Motor Controller and you will need 12V as well, without code to fire the Relay on the Power Distribution Board, you will need to hook up to the second port labeled Batt instead of 12V for this part. (This port ultimately powers the Raspberry Pi and you will need to hook up the Motor Control Module to the 12V line for normal use)

The current limit is a calculated with the following (simplified) equation:

VREF = 0.544Ω · IMAX

In our case the current limit for our motor is IMAX = 0.5A/phase

VREF = 0.27V
If you keep the driver hard-wired to full-steps, the motor only uses 70% of the max current, so the max current could technically be set to 0.7A, thus VREF = 0.38V .

The VREF test point is indicated on the bottom of the motor driver by a white circle. VREF can also be measured at the top of the potentiometer.

Motor Wiring

One coil (Blue/Red) 2B and 2A respectively on each motor controller module, the second coil (Green/Black) goes into 1A and 1B respectively on the left motor controller module, but 1B and 1A respectively on the right motor controller module. If the wheel turns in the wrong direction when testing, swap 1A and 1B on the coresponding motor controller module.

Ultrasonic Sensor Module

The large slot between the Raspberry Pi and the Snap Connectors is a pass-through for wires to reach the Ultrasonic Sensor Board on the bottom of the chassis.

Ferules: OPTIONAL but highly recommended

I added ferules to the wires to help install wires into the screw terminals (And the Snap connectors). We’re using 20AWG wire, but I had trouble fitting the 20AWG Ferules into the screw terminals. 22AWG ferules fit on the 20AWG wire and into the screw terminals I used. The motor wires are 26AWG so you will need 26AWG ferules for those wires. Any pre-tinned wires like the ones connected to the power switch should not need ferules attached.

Snap Connectors

The snap connectors have a dovetail mating interface. Slot a Yellow connector and a Green connector together.

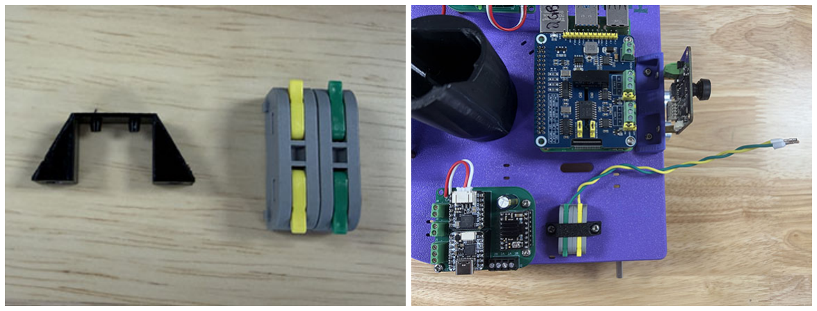
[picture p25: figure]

Slot the two nubs into the square holes on top of the snap connectors and screw the bracket down to the chassis with M3x6mm screws in the boxed pair of holes at the front right of the chassis.

Given the space constraints, it may be easier to install a pair of CAN wires into one end of the Snap Connectors before installing the connectors on the chassis. These wires should face towards the Raspberry Pi when the Snap Connectors are installed.

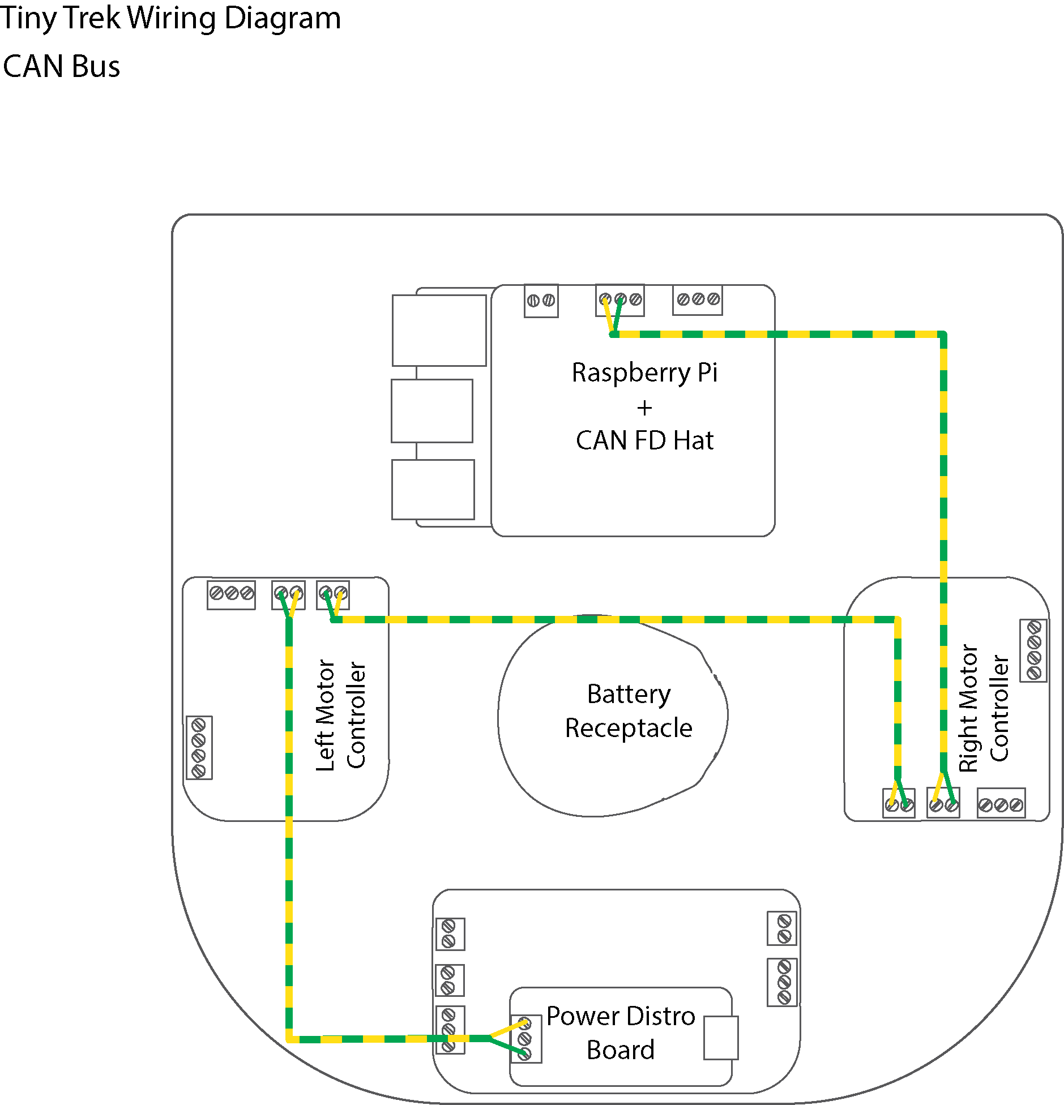
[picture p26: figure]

*Note: the CAN bus is a differential pair. This means the two wires should be as close to identical as possible and twisted together evenly along the full length with at least 1 twist per inch.

Terminating Resistors

The CAN Bus expects to have a 120Ω terminating resistor at each end of the bus. All of the CAN boards we used have terminating resitors installed, connected through a jumper circled in the photo above. In the above wiring configuration, the motor controllers are in the middle of the bus, so you have to cut the jumper on the top of the CAN BFF board. This can be done with a sharp hobby knife. The resistor on the Feather is also connected through a jumper with a cutable trace. We want to leave it in this configuration, but you may want to cut it depending on your wiring. The resistors on the two buses on the CAN FD Hat are connected through physical jumpers on headers. In this configuration, both jumpers should be in the ON position.

Optional Ultrasonic Sensor:

Make sure to double check the jumper on the Ultrasonic Senor Board is in the proper configuration for its location on the CAN bus. (not specified in this document)

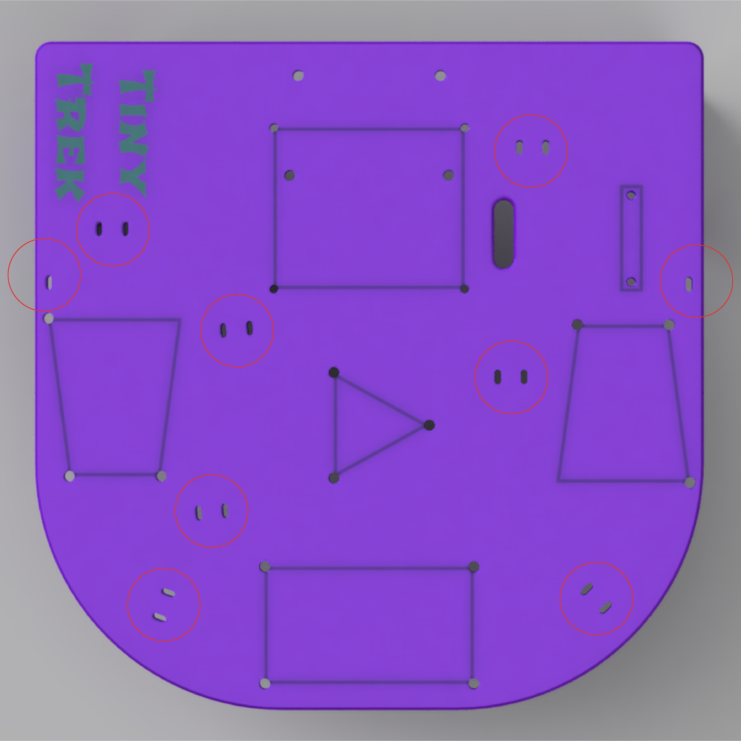
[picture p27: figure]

Once the wires have been routed, there are a few pairs of slots for wire management with 4” zipties. Near each motor there is a single slot. The ziptie is intended to wrap around the edge of the chassis here.

## Wheel Assembly

Parts:
- 1 pair Pololu Wheels
- 1 pair Pololu Wheel Hubs
- 4 x M3x8mm screws

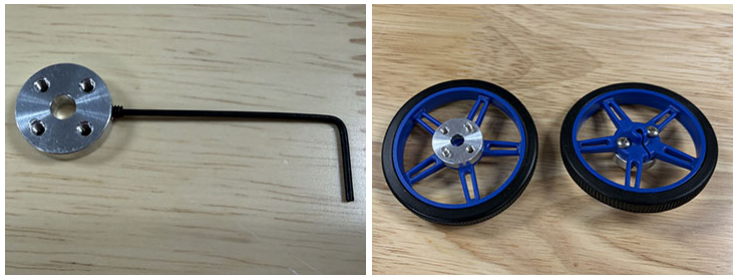
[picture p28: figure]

Install the set-screw in the wheel hub. Attach the hub to the wheel then install the assembly onto the motor shaft. The set-screw should line up with the flat side of the motor shaft.

## A Note about Programming the Microcontrollers:

All three of the QTPYs (on the Motor Control Modules and the Ultrasonic Sensor Module) and the Feather are on connected to the same 5V rail, so if you plug into their repective USB-C Ports, your computer will be trying to supply power to all four of these boards. The easiest way to make sure that doesn’t happen is to remove the QTPY or Feather you’re trying to program from the car entirely while you program it.

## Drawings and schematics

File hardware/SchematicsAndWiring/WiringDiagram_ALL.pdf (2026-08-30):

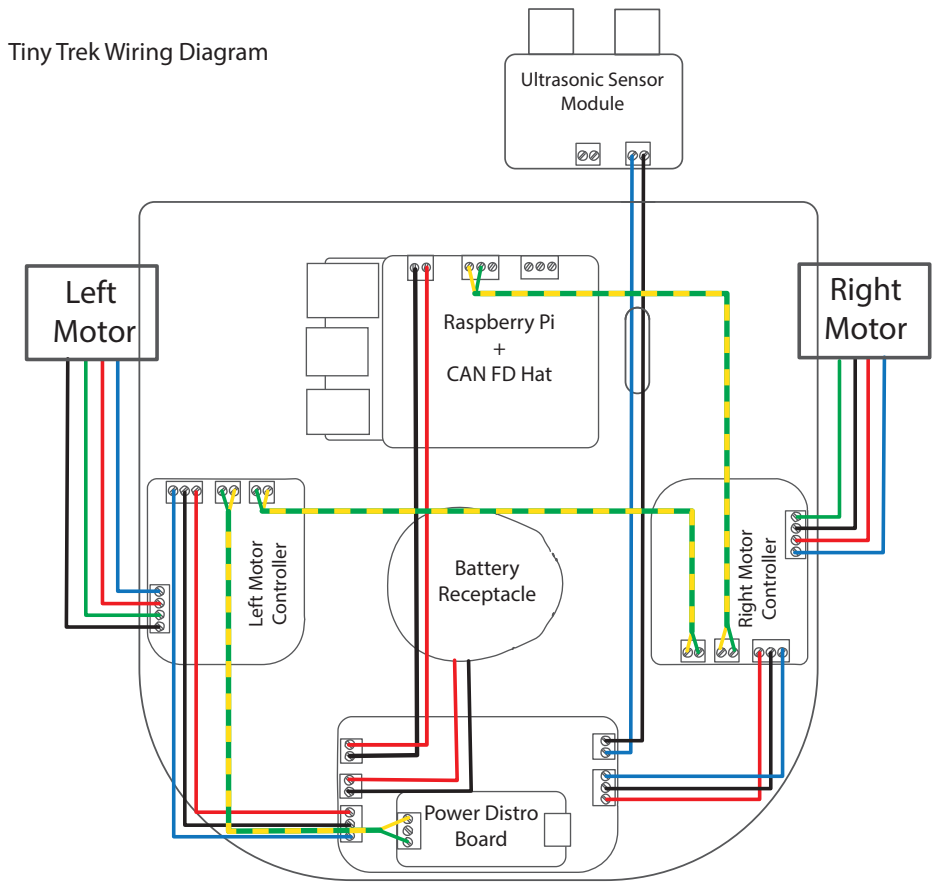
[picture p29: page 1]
Power Distro Board; Left Motor Controller; Right Motor Controller; Battery Receptacle; Left Motor; Right Motor; Ultrasonic Sensor Module

Tiny Trek Wiring Diagram

Raspberry Pi
CAN FD Hat

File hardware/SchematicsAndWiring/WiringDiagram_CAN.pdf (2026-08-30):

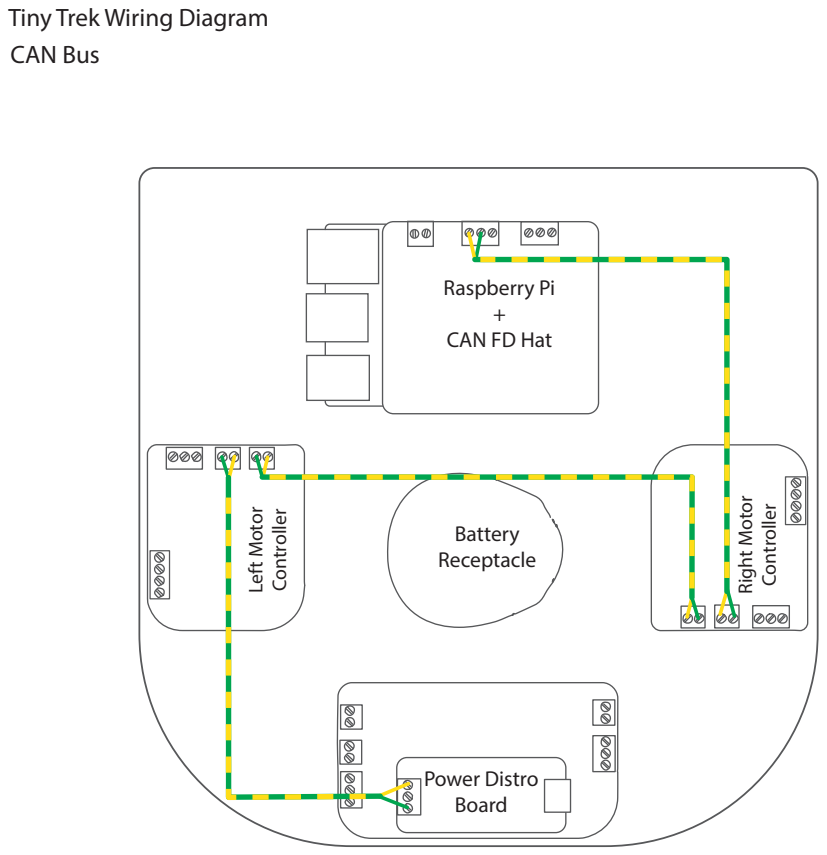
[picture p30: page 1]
Power Distro Board; Left Motor Controller; Right Motor Controller; Battery Receptacle; Left Motor; Right Motor; Power and Motors; Ultrasonic Sensor; Module

Tiny Trek Wiring Diagram
CAN Bus
w/ Optional Ultrasonic Sensor Module

Raspberry Pi
CAN FD Hat

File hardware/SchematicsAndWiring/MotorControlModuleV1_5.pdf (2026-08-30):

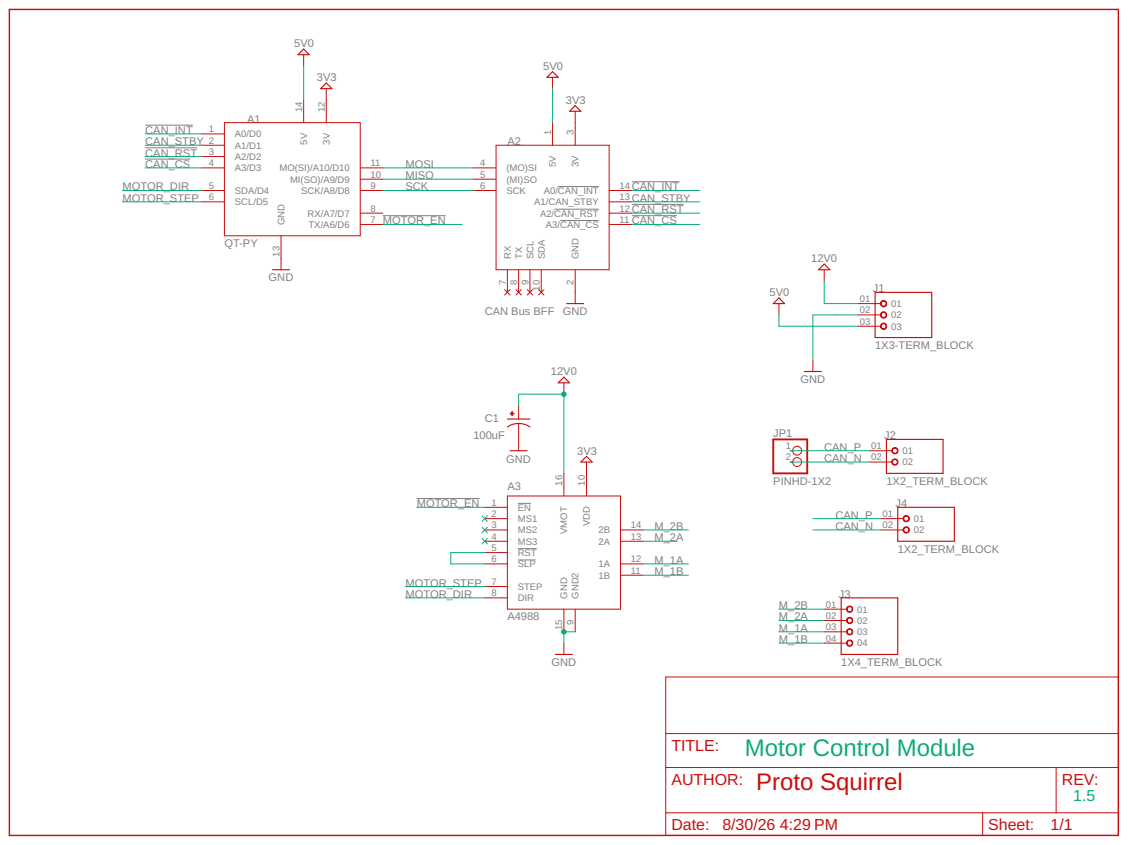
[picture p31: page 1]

AUTHOR: Proto Squirrel | REV: 1.5

Date: 8/30/26 4:29 PM | Sheet: 1/1

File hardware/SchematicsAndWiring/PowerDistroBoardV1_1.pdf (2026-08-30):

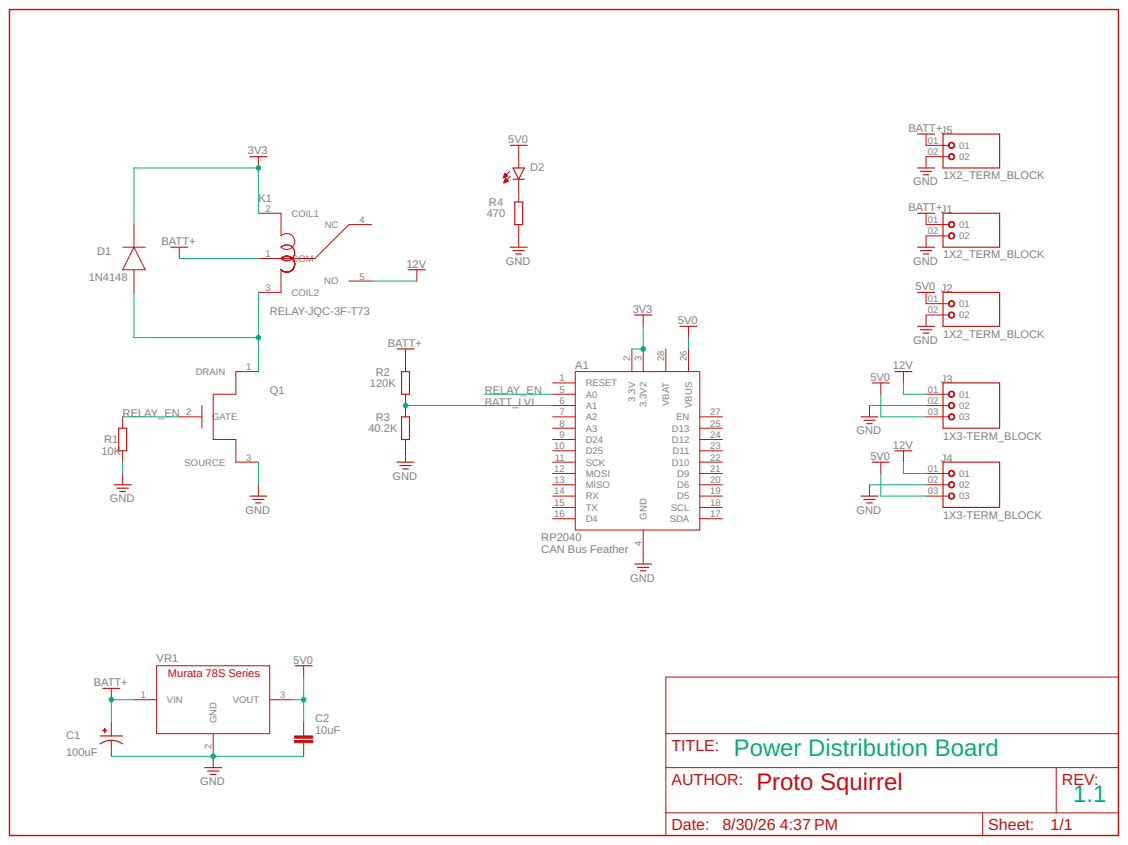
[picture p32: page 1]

AUTHOR: Proto Squirrel | REV: 1.1

Date: 8/30/26 4:37 PM | Sheet: 1/1

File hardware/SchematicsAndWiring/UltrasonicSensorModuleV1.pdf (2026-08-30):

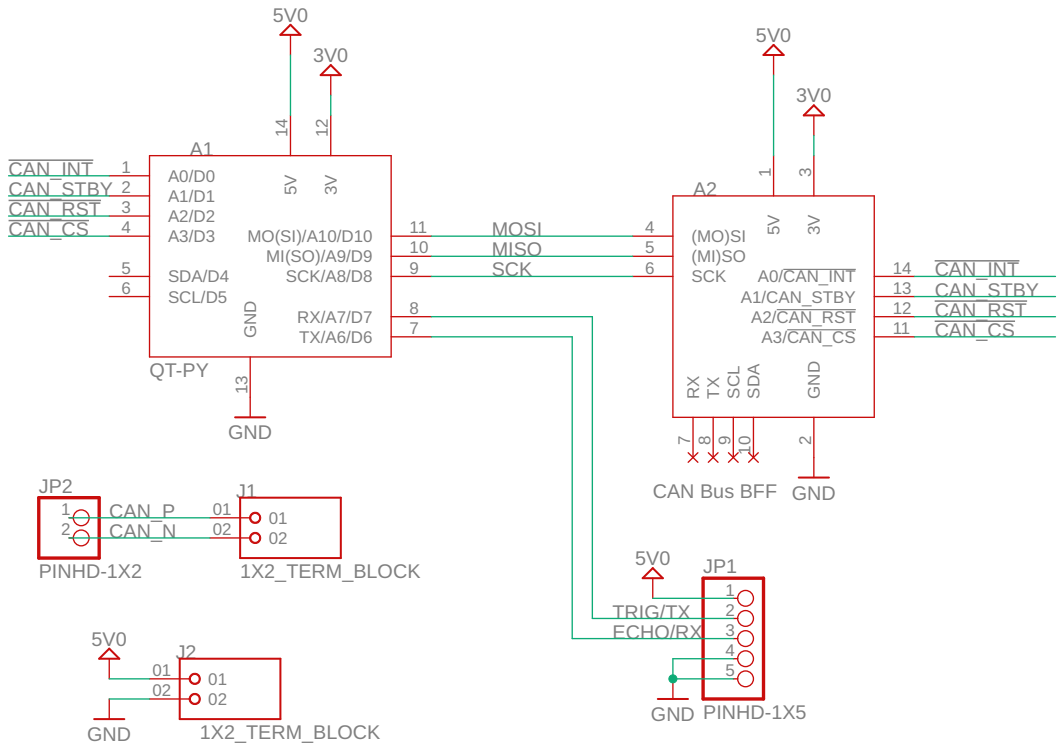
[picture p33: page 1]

AUTHOR: Proto Squirrel | 1.0 REV:

Date: 8/30/26 4:46 PM | Sheet: 1/1

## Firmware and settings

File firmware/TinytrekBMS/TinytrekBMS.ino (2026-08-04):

// Library sources live in this sketch folder so the Arduino IDE compiles them
// with no setup: open the .ino, pick the board, upload. QUOTED includes, not
// angle brackets -- the IDE adds the sketch directory to the quoted search
// path only, so <CAN.h> would not be found here.
#include "CAN.h"
#include "Adafruit_NeoPixel.h"

// --- CAN IDs ---
int canId = 0x115;         // RX: power command  [0x01]=on / [0x02]=off
int statusId = 0x116;      // TX: battery telemetry (Vbat millivolts, uint16 big-endian)

// ---- CTF challenge layer ---------------------------------------------------
// The BMS doubles as the DRIVE-bus MONITOR: it watches the motor command traffic it
// already receives and emits a flag frame on a signature no legitimate interface
// produces.
//
// NOTHING IS COMPILED IN. The Pi sends the unlock codes and detector thresholds
// during PROVISIONING -- an operator action, before the event -- and they are
// written to flash here. At runtime they are read from flash and nothing is
// transmitted, so the codes are never on the bus while a contestant is on it.
//
// A configured node IGNORES further config frames, so nobody who reaches the drive
// bus can overwrite them. Until provisioned this node detects nothing: an
// unprovisioned car has no challenge to protect, and staying quiet is the safe
// direction.
//
// The rules were prototyped and tuned against real timing on the bench before being
// brought here (bench/vehicle-emulator.py, bench/test-detectors.py) -- eight RP2040s
// are the slowest thing in this project to iterate on.
#include <EEPROM.h>

const long NODE_CFG_ID  = 0x101;   // RX: provisioning from the Pi
const uint8_t CFG_MAGIC = 0xC7;    // marks a written record; anything else = empty
const long HEARTBEAT_ID = 0x100;   // RX: [seq][armFlags]
const long L_MOTOR_ID   = 0x111;   // RX: monitored, never transmitted
const long R_MOTOR_ID   = 0x113;
const long C2_FLAG_ID   = 0x7D1;   // TX: C2 unlock code, 8 ASCII
const long C3_FLAG_ID   = 0x7D2;   // TX: C3 unlock code, 8 ASCII

// ARM MASK, mirrored from heartbeat byte 1. Bit SET = detector ARMED.
//
// POSITIVE ARMING, and the direction is the whole point. With redeemed-semantics a
// zero byte would mean ARMED, so any failure -- a Pi bug, a short frame, old
// firmware, a dropped heartbeat -- would leave detection live and the car would leak
// its unlock codes during ordinary driving. With arm-semantics those same failures
// leave detection DISARMED: the challenge does not fire, someone reports "this
// station is broken", and it gets fixed. A dead station is recoverable. A silently
// leaked flag is not.
const uint8_t ARM_C2 = 0x01;
const uint8_t ARM_C3 = 0x02;
const unsigned long HEARTBEAT_TIMEOUT_MS = 1000;  // stale heartbeat -> disarmed

const unsigned long HOLD_MS      = 1000;   // condition "still true" after last hit
const unsigned long FLAG_EMIT_MS = 500;    // 2 Hz while the condition holds
const uint8_t       C3_MAX       = 32;     // ring capacity; threshold is provisioned

// Provisioned by the Pi. Defaults are inert: with no codes there is nothing to
// emit, and detection stays off until cfgReady().
char          codeC2[9] = {0};
char          codeC3[9] = {0};
uint8_t       pivotRpm      = 0;     // the ONLY rpm legitimate locked traffic uses
unsigned long c2PairWindowMs = 250;
uint8_t       c3Count        = 15;
unsigned long c3WindowMs     = 3000;
bool          haveC2 = false, haveC3 = false, haveTuning = false;

// Which CHUNKS of each code have actually arrived: bit0 = chunk 0 (bytes 0-5),
// bit1 = chunk 1 (bytes 6-7). A code is complete only at 0x03.
//
// WHY THIS EXISTS. haveC2/haveC3 used to be set by the chunk-1 branch alone, so
// "I saw the last chunk" was taken to mean "I have the whole code". A node that
// missed chunk 0 -- exactly the case the Pi's 6-second repeat burst exists to
// cover, e.g. a replacement board still booting when provisioning ran -- would
// latch a code of six zero bytes plus two good ones, store it to EEPROM, and then
// refuse all further config because cfgReady() had flipped. It emits a garbage
// flag forever, and since cfgLoad() restores the latch from the magic byte it
// survives every reboot. There is no CAN or serial path to undo it: the board has
// to be physically erased. Chunks are cheap to count; do that instead.
uint8_t       c2Chunks = 0, c3Chunks = 0;

// Flash layout: [magic][C2 x8][C3 x8][pivotRpm][c2win/10][c3count][c3win/100]
static void cfgLoad() {
  EEPROM.begin(32);
  if (EEPROM.read(0) != CFG_MAGIC) return;
  for (uint8_t i = 0; i < 8; i++) { codeC2[i] = EEPROM.read(1 + i); codeC3[i] = EEPROM.read(9 + i); }
  pivotRpm       = EEPROM.read(17);
  c2PairWindowMs = (unsigned long)EEPROM.read(18) * 10;
  c3Count        = EEPROM.read(19); if (c3Count > C3_MAX) c3Count = C3_MAX;
  c3WindowMs     = (unsigned long)EEPROM.read(20) * 100;
  haveC2 = haveC3 = haveTuning = true;
  c2Chunks = c3Chunks = 0x03;   // a stored code is by definition complete
}

static void cfgStore() {
  EEPROM.write(0, CFG_MAGIC);
  for (uint8_t i = 0; i < 8; i++) { EEPROM.write(1 + i, codeC2[i]); EEPROM.write(9 + i, codeC3[i]); }
  EEPROM.write(17, pivotRpm);
  EEPROM.write(18, (uint8_t)(c2PairWindowMs / 10));
  EEPROM.write(19, c3Count);
  EEPROM.write(20, (uint8_t)(c3WindowMs / 100));
  EEPROM.commit();
}

static bool cfgReady() { return haveC2 && haveC3 && haveTuning && pivotRpm > 0; }

// codeSane -- does a stored code look like a code, rather than like wreckage?
// Eight characters, all from the generator's alphabet (upper alphanumerics).
static bool codeSane(const char* c) {
  for (uint8_t i = 0; i < 8; i++) {
    char ch = c[i];
    bool okch = (ch >= 'A' && ch <= 'Z') || (ch >= '0' && ch <= '9');
    if (!okch) return false;
  }
  return true;
}

// cfgReport prints what this node believes, periodically, on the serial port.
//
// WHY IT EXISTS: the stored config lives in flash, NOT on the Pi's SD card, so it
// survives reflashing the Pi and (depending on the upload path) may survive
// reflashing this sketch. A board that latched a malformed code under the old
// chunk-completeness bug therefore stays broken after both -- cfgLoad() sees the
// magic byte, restores the wreckage, and cfgReady() goes true, so the node refuses
// all further code config. Until now nothing reported that, and the first symptom
// would have been a garbage flag frame mid-event.
//
// DELIBERATELY PRINTS A FINGERPRINT, NOT THE CODES. This is a USB serial port on a
// board inside a car that contestants have physical access to. The fingerprint is
// enough to compare two boards, or to spot obvious wreckage, without disclosing
// anything. sane=no means: erase this board's config and re-provision it.
static unsigned long lastCfgReport = 0;
const unsigned long CFG_REPORT_MS = 5000;

static void cfgReport() {
  // PERIODIC, NOT ONCE AT BOOT. This is a native-USB board: a reset drops the CDC
  // connection, so anything setup() prints is gone before a serial monitor can
  // reattach. The motor sketches learned this the hard way -- their original
  // one-shot "Failed to initialize CAN BUS." message was never seen by anyone.
  // Attaching a monitor at ANY time must tell you the current state.
  if (lastCfgReport != 0 && millis() - lastCfgReport < CFG_REPORT_MS) return;
  lastCfgReport = millis();

  Serial.print("cfg: ");
  if (!cfgReady()) {
    Serial.println("UNCONFIGURED -- waiting for the Pi's 0x101 burst (this is normal on a new board)");
    return;
  }
  uint8_t fp = 0;
  for (uint8_t i = 0; i < 8; i++) { fp ^= (uint8_t)codeC2[i]; fp = (uint8_t)((fp << 1) | (fp >> 7)); }
  for (uint8_t i = 0; i < 8; i++) { fp ^= (uint8_t)codeC3[i]; fp = (uint8_t)((fp << 1) | (fp >> 7)); }
  Serial.print("CONFIGURED  fingerprint=0x");
  if (fp < 16) Serial.print("0");
  Serial.print(fp, HEX);
  Serial.print("  sane=");
  Serial.print((codeSane(codeC2) && codeSane(codeC3)) ? "yes" : "NO");
  Serial.print("  pivotRpm="); Serial.print(pivotRpm);
  Serial.print(" c2win="); Serial.print(c2PairWindowMs);
  Serial.print(" c3count="); Serial.print(c3Count);
  Serial.print(" c3win="); Serial.println(c3WindowMs);
  if (!(codeSane(codeC2) && codeSane(codeC3))) {
    Serial.println("cfg: *** STORED CODES ARE MALFORMED -- this node will emit garbage flags.");
    Serial.println("cfg: *** Erase it (double-tap RESET, drag flash_nuke.uf2) and reflash, then");
    Serial.println("cfg: *** re-run 'sudo ttos-provision-nodes' on the car.");
  }
}

uint8_t       armMask = 0;
unsigned long lastHeartbeatMs = 0;
bool          haveHeartbeat = false;

uint8_t       lastDir[2]  = {0, 0};      // [0]=L, [1]=R
uint8_t       lastRpm[2]  = {0, 0};
unsigned long lastCmdMs[2] = {0, 0};

unsigned long c2HoldUntil = 0;
unsigned long c3HoldUntil = 0;
unsigned long c3Hits[C3_MAX];
uint8_t       c3Head = 0, c3Len = 0;
unsigned long lastFlagMs = 0;

// --- Battery sense (A1) ------------------------------------------------------
// 120k high-side / 40.2k low-side divider (0.5%), fed to A1.
//   Vadc = Vbat * 40.2 / (120 + 40.2)  ->  Vbat = Vadc * (160.2 / 40.2) = Vadc * 3.985
// ADC_REF_MV is the analog reference in millivolts. The node is a 3.3V board
// (RP2040 / Feather RP2040 CAN), and Arduino analogRead defaults to 10-bit.
// Fine-tune ADC_REF_MV against a multimeter reading if the gauge is slightly off.
const int   BATT_PIN    = A1;
const long  ADC_REF_MV  = 3300;   // 3.3V board (RP2040). 5V board (UNO) -> 5000.
const int   ADC_MAX     = 1023;   // 10-bit analogRead default
const float DIVIDER     = (120.0 + 40.2) / 40.2;  // = 3.985
// Beacon period. This message is not just the battery gauge: the motor nodes use
// it as the "12V rail is really on" signal and light red without it, so it runs at
// 5 Hz (their timeout is 1 s = 5 missed beacons) rather than the old 1 Hz.
const unsigned long TELEM_MS = 200;               // beacon period (~5 Hz)

// --- Pack range / gauge bands -----------------------------------------------
// Same 3S range the dashboard maps: 8.4 V = 0%, 12.3 V = 100%.
//   50% -> 8400 + 0.50*(12300-8400) = 10350 mV
//   25% -> 8400 + 0.25*(12300-8400) =  9375 mV
const long BATT_MIN_MV  = 8400;    // 0%
const long BATT_MAX_MV  = 12300;   // 100%
const long BATT_50_MV   = BATT_MIN_MV + (BATT_MAX_MV - BATT_MIN_MV) * 50 / 100;  // 10350
const long BATT_25_MV   = BATT_MIN_MV + (BATT_MAX_MV - BATT_MIN_MV) * 25 / 100;  //  9375

// --- Low-voltage cutoff (protect a 3S pack) ---------------------------------
// Below CUTOFF the 12V rail is forced off; it stays locked out until the pack
// recovers above RECOVER (hysteresis stops it chattering near the threshold).
const long LVC_CUTOFF_MV  = 8500;  // cut 12V just above 0% (8.4V)
const long LVC_RECOVER_MV = 9000;  // re-allow power on above this
// Debounce: motor inrush briefly sags the pack when the 12V rail energizes, so a
// single sub-cutoff sample must NOT latch lockout. The pack has to stay below
// cutoff continuously for this long before the rail is cut.
const unsigned long LVC_TRIP_MS = 1500;

// --- Status NeoPixel (onboard on the Feather RP2040 CAN) --------------------
// Blink encodes the 12V relay; color encodes the battery band. Fast blink is
// reserved for the low-voltage cutoff (see the table in firmware/README.md).
//   solid       = 12V inactive        slow blink = 12V active (enabled)
//   green >=50%  amber 25..50%  red <25%      fast-blink red = below cutoff
#ifdef PIN_NEOPIXEL
Adafruit_NeoPixel pixel(1, PIN_NEOPIXEL, NEO_GRB + NEO_KHZ800);
#else
// Fall back to the Adafruit stock pin if the variant doesn't define one.
Adafruit_NeoPixel pixel(1, 16, NEO_GRB + NEO_KHZ800);
#endif
const uint8_t LED_BRIGHTNESS = 64;       // 0..255; keep it non-blinding
const unsigned long BLINK_SLOW_MS = 600; // "enabled" half-period
const unsigned long BLINK_FAST_MS = 150; // "cutoff" half-period
const unsigned long LED_UPDATE_MS = 25;  // don't hammer show()

unsigned long lastTelem  = 0;
unsigned long lastLed    = 0;
unsigned long belowSince = 0;            // when the pack first dropped below cutoff (0 = not below)
uint32_t      ledLast    = 0xFFFFFFFF;   // force first show()
bool lvcLockout = false;
bool power12v   = false;                 // tracks the 12V relay for the LED

void setup() {
  cfgLoad();   // provisioned values from flash; nothing is transmitted at runtime
  Serial.begin(115200);

  Serial.println("Initializing GPIO");
  pinMode(A0, OUTPUT);      // 12V rail control
  pinMode(13, OUTPUT);
  pinMode(BATT_PIN, INPUT); // battery sense

  // Some Adafruit RP2040 variants gate NeoPixel power behind a pin.
#ifdef NEOPIXEL_POWER
  pinMode(NEOPIXEL_POWER, OUTPUT);
  digitalWrite(NEOPIXEL_POWER, HIGH);
#endif
  pixel.begin();
  pixel.setBrightness(LED_BRIGHTNESS);
  pixel.clear();
  pixel.show();

  CAN.setPins(PIN_CAN_CS, PIN_CAN_INTERRUPT);

  Serial.println("Initializing CAN");
  if (!CAN.begin(500000)) {
    Serial.println("Failure Initializing CAN.");
  }

  powerOff();
}

// updateLed maps (12V state, battery band, cutoff) onto the onboard pixel.
// Non-blocking: throttled to LED_UPDATE_MS and only calls show() on a change.
void updateLed(long vbatMv) {
  if (millis() - lastLed < LED_UPDATE_MS) return;
  lastLed = millis();

  uint8_t r, g, b;
  unsigned long period;   // 0 = solid

  if (lvcLockout) {
    r = 255; g = 0; b = 0;            // below cutoff: fast-blink red, 12V off
    period = BLINK_FAST_MS;
  } else {
    if (vbatMv >= BATT_50_MV)      { r = 0;   g = 255; b = 0; }   // green
    else if (vbatMv >= BATT_25_MV) { r = 255; g = 120; b = 0; }   // amber
    else                           { r = 255; g = 0;   b = 0; }   // red
    period = power12v ? BLINK_SLOW_MS : 0;                        // slow if enabled
  }

  bool on = (period == 0) ? true : (((millis() / period) & 1UL) == 0);
  uint32_t c = on ? pixel.Color(r, g, b) : 0;
  if (c != ledLast) {
    pixel.setPixelColor(0, c);
    pixel.show();
    ledLast = c;
  }
}

// readVbatMv averages a few samples to steady the reading.
long readVbatMv() {
  long acc = 0;
  for (int i = 0; i < 8; i++) acc += analogRead(BATT_PIN);
  long adc = acc / 8;
  long vadcMv = adc * ADC_REF_MV / ADC_MAX;      // millivolts at A1
  long vbatMv = (long)(vadcMv * DIVIDER + 0.5);  // millivolts at the pack
  if (vbatMv < 0) vbatMv = 0;
  if (vbatMv > 65535) vbatMv = 65535;
  return vbatMv;
}
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
void loop() {
  int packetSize = CAN.parsePacket();

  if(CAN.packetId() == canId) {
    char buf[8] = {0};
    CAN.readBytes(buf, CAN.packetDlc());

    if(buf[0] == 0x1) {
      if(!lvcLockout) powerOn();   // refuse power-on while the pack is too low
    } else if(buf[0] == 0x2) {
      powerOff();
    }
  }
  else if (packetSize > 0) {
    long rxId = CAN.packetId();
    int  rxDlc = CAN.packetDlc();
    uint8_t rb[8] = {0};
    CAN.readBytes((char*)rb, rxDlc);

    if (rxId == NODE_CFG_ID && rxDlc >= 2) {
      // [type][idx][payload]. Codes arrive as two 6-byte chunks.
      //
      // CODES are write-once: accepted only while unconfigured, so nothing on the
      // bus can rewrite the answers on a car that is already in play. TUNING is
      // NOT, deliberately -- see the 0x20 case.
      bool locked = cfgReady();
      bool dirty  = false;
      switch (rb[0]) {
        case 0x10:
          if (locked) break;
          if (rb[1] == 0) { memcpy(codeC2,     &rb[2], 6); c2Chunks |= 0x01; }
          else            { memcpy(codeC2 + 6, &rb[2], 2); c2Chunks |= 0x02; }
          haveC2 = (c2Chunks == 0x03);
          break;
        case 0x11:
          if (locked) break;
          if (rb[1] == 0) { memcpy(codeC3,     &rb[2], 6); c3Chunks |= 0x01; }
          else            { memcpy(codeC3 + 6, &rb[2], 2); c3Chunks |= 0x02; }
          haveC3 = (c3Chunks == 0x03);
          break;
        case 0x20:
          // TUNING IS ACCEPTED EVEN WHEN ALREADY PROVISIONED, and that is the point.
          //
          // The whole 0x101 handler used to be gated on !cfgReady(), so a provisioned
          // node silently discarded this record. The operator path says otherwise:
          // ttos-dashboard.default tells you to raise the pivot rpm if the car grinds
          // at 75, and ttos-provision-nodes says to re-run after changing it. The
          // burst went out, the script printed done, and the BMS kept the old value.
          //
          // That divergence is not cosmetic. C3's discriminator is "same direction AND
          // an rpm the pivot never uses". If the Pi pivots at 150 while this node still
          // believes 75, a team replaying captured pivot frames satisfies both halves
          // and collects the C3 code with no forgery at all -- defeating the property
          // ARCHITECTURE.md section 6 calls mechanical rather than policy.
          //
          // Safe to leave open: 0x101 is refused by the C3 relay's SEND path and is not
          // in the C2 bridge allowlist, so no contestant-reachable path can inject it.
          if (rxDlc >= 6) {
            uint8_t       newRpm   = rb[2];
            unsigned long newPair  = (unsigned long)rb[3] * 10;
            uint8_t       newCount = rb[4] > C3_MAX ? C3_MAX : rb[4];
            unsigned long newWin   = (unsigned long)rb[5] * 100;
            dirty = locked && (newRpm != pivotRpm || newPair != c2PairWindowMs ||
                               newCount != c3Count || newWin != c3WindowMs);
            pivotRpm       = newRpm;
            c2PairWindowMs = newPair;
            c3Count        = newCount;
            c3WindowMs     = newWin;
            haveTuning     = true;
          }
          break;
      }
      if (!locked && cfgReady()) {
        cfgStore();
        Serial.println("provisioned: codes and thresholds stored, detection ARMED");
      } else if (dirty) {
        // Persist a retune so it survives the next power cycle, exactly as the
        // original provisioning does.
        cfgStore();
        Serial.print("retuned: pivotRpm="); Serial.print(pivotRpm);
        Serial.print(" c2win="); Serial.print(c2PairWindowMs);
        Serial.print(" c3count="); Serial.print(c3Count);
        Serial.print(" c3win="); Serial.println(c3WindowMs);
      }
    } else if (rxId == HEARTBEAT_ID) {
      lastHeartbeatMs = millis();
      haveHeartbeat = true;
      // DLC < 2 means no flags field, so no arming information -> DISARMED.
      armMask = (rxDlc >= 2) ? rb[1] : 0;
    } else if (rxId == L_MOTOR_ID || rxId == R_MOTOR_ID) {
      // Monitor ONLY. The BMS never validates the CRC and never acts on these --
      // it is watching the shape of the traffic, not obeying it. Frames the motors
      // will silently reject still count, which is correct: a contestant hammering
      // the bus with bad CRCs is still commanding, and the signature is the intent.
      if (rxDlc >= 6) noteCommand(rxId == L_MOTOR_ID ? 0 : 1, rb[4], rb[5]);
    }
  }

  // Stale heartbeat -> disarm. Fail-safe direction, same 1 s timeout the motor
  // nodes already use.
  if (haveHeartbeat && (millis() - lastHeartbeatMs) >= HEARTBEAT_TIMEOUT_MS) armMask = 0;

  // Emit at 2 Hz while a condition holds, rather than once when it trips. A
  // single-shot emission would make the challenge a coin flip on whether the
  // contestant happened to be capturing at that instant; repeating it means
  // someone who solved it without a sniffer running can simply do it again.
  if (millis() - lastFlagMs >= FLAG_EMIT_MS) {
    lastFlagMs = millis();
    if (cfgReady()) {
      if ((armMask & ARM_C2) && millis() < c2HoldUntil) emitFlag(C2_FLAG_ID, codeC2);
      if ((armMask & ARM_C3) && millis() < c3HoldUntil) emitFlag(C3_FLAG_ID, codeC3);
    }
  }

  // Low-voltage cutoff, debounced so motor-inrush sag doesn't cut the rail.
  // Latch only after the pack stays below cutoff for LVC_TRIP_MS continuously;
  // clear via hysteresis once it recovers above RECOVER.
  long vbatMv = readVbatMv();
  if (vbatMv < LVC_CUTOFF_MV) {
    if (belowSince == 0) belowSince = millis();
    if (!lvcLockout && (millis() - belowSince >= LVC_TRIP_MS)) {
      lvcLockout = true;
      powerOff();
      Serial.print("LVC: cutoff latched, 12V off at "); Serial.print(vbatMv); Serial.println(" mV");
    }
  } else {
    belowSince = 0;                       // back above cutoff: reset the debounce timer
    if (lvcLockout && vbatMv > LVC_RECOVER_MV) {
      lvcLockout = false;
      Serial.print("LVC: recovered at "); Serial.print(vbatMv); Serial.println(" mV");
    }
  }

  // Beacon: [v_hi][v_lo][pwr][flags] at ~5 Hz.
  //   pwr   0x01 = 12V rail on, 0x02 = off (same encoding as the 0x115 command)
  //   flags bit0 = low-voltage cutoff latched (explains WHY the rail is off)
  // The motor nodes gate their READY (green) state on this message, so it must
  // keep flowing whenever the BMS is alive.
  if (millis() - lastTelem >= TELEM_MS) {
    lastTelem = millis();
    CAN.beginPacket(statusId);
    CAN.write((vbatMv >> 8) & 0xFF);   // high byte
    CAN.write(vbatMv & 0xFF);          // low byte
    CAN.write(power12v ? 0x01 : 0x02); // actual rail state (not the commanded one)
    CAN.write(lvcLockout ? 0x01 : 0x00);
    CAN.endPacket();
  }

  // Drive the status pixel from the current 12V + battery + cutoff state.
  updateLed(vbatMv);

  // And say what this node believes, on the serial port, continuously. Self
  // throttled to CFG_REPORT_MS.
  cfgReport();
}

void powerOn() {
  digitalWrite(A0, HIGH);
  power12v = true;
}

void powerOff() {
  digitalWrite(A0, LOW);
  power12v = false;
}

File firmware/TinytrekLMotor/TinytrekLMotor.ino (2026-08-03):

/*
TinyTrek LEFT stepper motor node (CAN id 0x111).
Microcontroller: Adafruit QT Py SAMD21 + MCP2515 CAN (CS=3, INT=0).
Identical to TinytrekRMotor except for canId -- keep the two in sync.
*/

// Library sources live in this sketch folder so the Arduino IDE compiles them
// with no setup: open the .ino, pick the board, upload. QUOTED includes, not
// angle brackets -- the IDE adds the sketch directory to the quoted search
// path only, so <CAN.h> would not be found here.
#include "CAN.h"
#include "Adafruit_NeoPixel.h"

const int dirPin = 4;
const int stepPin = 5;
const int enablePin = 6;

int FORWARD = HIGH;
int BACKWARD = LOW;

// Steps for one revolution on stepper motor
int stepsPerRev = 200;

// Desired speed
int rpm = 100;

int canId = 0x111;

// --- Consumed step buffer (tolerates dropped CAN frames) --------------------
// Each command ADDS steps to a buffer (capped) and sets speed/direction; the
// motor drains the buffer as it steps, so motion follows the BUFFER, not message
// timing. A dropped frame or two doesn't stall it while the buffer holds steps --
// that smooths over intermittent CAN loss. The cap bounds how far it coasts and
// makes runaway impossible: if commands stop, it empties and halts within
// STEPS_MAX steps. dir 0x00, or a change of direction, clears the buffer.
const long STEPS_MAX = 250;   // ~2.5x the dashboard's per-frame chunk -> jitter cushion

long          stepsLeft  = 0;      // steps still to run (the consumed buffer)
int           driveDir   = FORWARD;
int           driveRpm   = 100;
unsigned long lastStepUs = 0;
bool          driverOn   = false;

// --- System-state inputs (for the status LED) -------------------------------
// The node watches two periodic messages so the LED reports the health of the
// WHOLE chain, not just this board -- which is what makes it a wiring-diagnosis
// tool: whatever is missing tells you which link is broken.
//   0x100 heartbeat from the Pi  : [seq][flags]        -- "the Pi is alive + in control"
//   0x116 beacon from the BMS    : [v_hi][v_lo][pwr][flags] -- "12V rail is really on"
// pwr: 0x01 = 12V on, 0x02 = off (same encoding as the 0x115 command).
// ---- node provisioning: pushed ONCE, then stored ---------------------------
// The Pi sends this node its Data ID during PROVISIONING -- an operator action,
// performed before the event -- and the node writes it to flash. At runtime it is
// read from flash and NOTHING IS TRANSMITTED, so the value that Challenge 3 exists
// to recover is never on the bus while a contestant is on it.
//
// A configured node IGNORES further config frames. Otherwise anyone who reached the
// drive bus could simply overwrite the Data ID with one they already knew and forge
// freely, which would turn Challenge 3 into "get relay access". Re-provisioning a
// node means erasing it deliberately (hold-to-erase at boot, below) or reflashing.
//
// UNCONFIGURED IS PERMISSIVE: a node with nothing stored accepts the unprotected
// 6-byte command, because an unprovisioned car must still drive. That is fail-open,
// and it is covered -- the Pi's bridge and relay, the only two routes a contestant
// has onto this bus, validate protection independently.
#include "FlashAsEEPROM.h"

const long NODE_CFG_ID = 0x101;
const uint8_t CFG_MAGIC = 0xC7;   // marks a written record; anything else = empty

bool     haveDataId = false;
uint16_t myDataId   = 0;

static void cfgLoad() {
  if (!EEPROM.isValid()) return;
  if (EEPROM.read(0) != CFG_MAGIC) return;
  myDataId   = ((uint16_t)EEPROM.read(1) << 8) | EEPROM.read(2);
  haveDataId = true;
}

static void cfgStore(uint16_t id) {
  EEPROM.write(0, CFG_MAGIC);
  EEPROM.write(1, (uint8_t)(id >> 8));
  EEPROM.write(2, (uint8_t)(id & 0xFF));
  EEPROM.commit();               // one flash-page write; provisioning only
  myDataId   = id;
  haveDataId = true;
}

// CRC-8/SAE-J1850 (poly 0x1D, init 0xFF, xorout 0xFF) keyed by a 16-bit Data ID,
// AUTOSAR E2E Profile 1 style: Data ID prefixed LOW BYTE FIRST, then the covered
// bytes. Must match protectionCRC() in cmd/dashboard/protect.go byte for byte.
// Check value: over "123456789" with no key, 0x4B.
static uint8_t crc8J1850Keyed(const uint8_t* data, uint8_t len, uint16_t dataId) {
  uint8_t crc = 0xFF;
  uint8_t pre[2] = { (uint8_t)(dataId & 0xFF), (uint8_t)(dataId >> 8) };
  for (uint8_t i = 0; i < 2; i++) {
    crc ^= pre[i];
    for (uint8_t b = 0; b < 8; b++) crc = (crc & 0x80) ? (uint8_t)((crc << 1) ^ 0x1D) : (uint8_t)(crc << 1);
  }
  for (uint8_t i = 0; i < len; i++) {
    crc ^= data[i];
    for (uint8_t b = 0; b < 8; b++) crc = (crc & 0x80) ? (uint8_t)((crc << 1) ^ 0x1D) : (uint8_t)(crc << 1);
  }
  return crc ^ 0xFF;
}

const long HEARTBEAT_ID  = 0x100;
const long BMS_BEACON_ID = 0x116;
// Both are sent at ~5 Hz, so 1 s is 5 missed messages -- slow enough not to
// flicker on a busy bus, fast enough to see a cable pulled.
const unsigned long HEARTBEAT_TIMEOUT_MS = 1000;
const unsigned long BEACON_TIMEOUT_MS    = 1000;

unsigned long lastHeartbeatMs = 0;
unsigned long lastBeaconMs    = 0;
bool          haveHeartbeat   = false;   // distinct from "millis()==0 at boot"
bool          haveBeacon      = false;
bool          beacon12v       = false;   // last reported 12V rail state

// --- CAN bring-up -----------------------------------------------------------
// The MCP2515 needs its oscillator running before it will answer over SPI: 128
// oscillator cycles for the start-up timer PLUS crystal settling, which from a
// cold power-on is hundreds of microseconds to milliseconds. The library's
// reset() waits only 10us, so begin()'s CANCTRL readback can lose that race at
// power-on and succeed on a warm reset.
//
// A board that loses it used to stay deaf FOREVER: begin() failed, the message was
// printed to a serial port nobody was attached to, and setup() carried on. The
// controller sits in configuration mode -- electrically passive, so it neither
// acknowledges frames nor corrupts the bus. From the Pi the bus looks perfectly
// healthy (another node ACKs) while this node hears nothing. Diagnosed exactly
// once, the hard way, on 2026-08-02.
//
// So: settle before the first attempt, and RETRY until it works.
const long CAN_BITRATE = 500000;

// MCP2515 module crystal. begin() does NOT verify this -- it picks bit timing from
// whatever we claim here, so an 8 MHz module told 16 MHz reports success and then
// runs at half rate (deaf, and it corrupts the bus with error frames). Override at
// build time for 8 MHz modules: --build-property "build.extra_flags=-DCAN_CLOCK_HZ=8000000"
#ifndef CAN_CLOCK_HZ
#define CAN_CLOCK_HZ 16000000L
#endif
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

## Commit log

2026-07-29 Initial TTOS CTF baseline layer, container, and kas build
    New repository (not a fork of sixvolts/TinyTrek, per brief §3): a minimal
    scarthgap Yocto image for the CTF vehicle (RPi4 + Waveshare 2-CH CAN FD HAT
    Rev2.1). Boots, brings up both CAN interfaces and a WiFi AP; no challenge logic.
    Ported deliberately from tinytrekos/meta-tt, fixing every §4 defect:
    - 4.1 CAN kconfig moved to linux-raspberrypi bbappend (was dead on linux-yocto);
    added CONFIG_CAN_MCP251XFD, kept CONFIG_CAN_GW.
    - 4.2 committed WiFi creds removed; SSID/PSK are first-boot provisioning only.
    - 4.3 private git.faro.re tinytrek recipe dropped; container keyscan/agent gone.
    - 4.4 SSTATE_CACHE (no-op) -> SSTATE_DIR, ou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
    [can_config.cfg]
2026-07-29 socketcand: fix build on modern toolchain; correct image path in README
    socketcand 0.6.1 failed do_compile against gcc 13.4 / glibc:
    - SIOCGSTAMP undeclared (glibc >= 2.30 dropped it from <sys/ioctl.h>)
    - multiple definition of tv/readfds/ifr (gcc >= 10 -fno-common default)
    Fixed with CFLAGS += "-DSIOCGSTAMP=0x8906 -fcommon". Verified: compile,
    install, and packaging all succeed; socketcand + socketcandcl binaries and
    ipk packages produced.
    README: image deploy path is tmp-glibc/ (poky TCLIBCAPPEND), not tmp/.
2026-07-29 image: stage CAN overlays with correct IMAGE_BOOT_FILES syntax
    do_image_wic failed staging the CAN overlays: the entries used a bare
    'overlays/mcp251xfd.dtbo' source path, but the kernel deploys overlays flat.
    Corrected to '<deploy-file>;<dest>' (mcp251xfd.dtbo;overlays/mcp251xfd.dtbo),
    matching meta-raspberrypi's own make_dtb_boot_files convention. These two
    overlays are not in the default KERNEL_DEVICETREE set, so explicit entries are
    required. Also dropped a redundant 'dtparam=spi=on' (ENABLE_SPI_BUS already adds it).
    Verified in the built .wic boot partition: overlays/mcp251xfd.dtbo +
    overlays/spi1-3cs.dtbo present; config.txt and cmdline.txt (console=serial0,
    no U-Boot) correct. Full i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
2026-07-30 provision: ship ttos-provision.conf.example on the FAT boot partition
    So a freshly-flashed card already carries the provisioning template on the FAT
    partition (editable from any laptop) -- no need to fetch it from the build box,
    edit, and drop it on the card. ttos-provision now inherits deploy (machine-
    specific, so no longer allarch) and stages the example into DEPLOY_DIR_IMAGE;
    the image adds it to IMAGE_BOOT_FILES.
    Parse-checked (0 errors); takes effect on the NEXT image build. Current flashed
    image is unchanged.
2026-07-30 cangw + self-test robustness (real system was fine; test lied)
    On-hardware run showed CAN + WiFi AP actually working; the failures were a
    missing package and self-test bugs:
    - cangw lives in the can-utils-access subpackage, not can-utils -> install it
    (fixes the §4.1 go/no-go tool). No socketcand conflict: can-utils didn't build
    socketcand, so -access only ships cangw/bcmserver/canlogserver.
    - self-test CAN check looked for 'state UP', but CAN interfaces report operstate
    UNKNOWN when up -> check the admin <,UP,> flag instead, with a readiness wait.
    (networkctl confirmed both links 'configured', can1 MTU 72 = FD.)
    - wait up to 20s for ttos-ap: it reaches AP-ENABLED ~30s post-boot, a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
2026-07-30 Add ttos-dashboard: read-only live CAN monitor (Go, SSE), wired into Yocto
    Foundation for the CTF control panel. A dependency-free Go service that binds a
    raw SocketCAN socket (AF_CAN, CAN_RAW_FD_FRAMES) to each interface and streams
    every frame to the browser over Server-Sent Events. Read-only, so SSE fits and
    no websocket dependency is needed; stdlib only, so the binary is fully static
    (CGO off) and the Yocto recipe needs no module fetching or vendoring.
    - internal/canbus: raw SocketCAN reader/writer, classic + FD frames.
    - internal/sse: fan-out hub, drops slow clients rather than stalling readers.
    - cmd/dashboard: SSE server + embedded dark UI (live table, per-bus colouring,
    stat tiles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
2026-07-30 dashboard: operator console redesign (tabs, indicators, controls, 12V)
    Reworked the read-only monitor into the operator console from the sketch:
    - Header: "Tiny Trek" logo in Shojumaru (embedded via go:embed) + car id/host
    from /api/info (hostname, /etc/ttos/car-id).
    - Left: tabbed console -- Debug (default, live log) + one live-frame tab per bus,
    each with an activity dot and frames/s.
    - Right: 12V ACTIVE banner (prominent, pulses green when active), Battery bar,
    Sensors (U-Sonic/Camera) and Network (WiFi/Ethernet) indicators, and a control
    pad (forward/back/left/right, rotate CW/CCW, octagonal STOP).
    Backend now emits typed SSE events (frame/log/status) over one channel. New
    POST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
2026-07-30 provision: fix first-boot mount race (order after boot mount + wait)
    First boot could run ttos-provision before the FAT boot partition finished
    mounting, so it found no file, failed loud, and only succeeded on a later boot.
    Add RequiresMountsFor=/boot /boot/firmware to order after (and pull in) the
    mount, and a bounded ~20s wait in the script for the file to appear.
2026-07-31 dashboard: motion controls grounded on the stepper firmware
    Read the node firmware (TinytrekLMotor/RMotor/BMS): motors are STEPPERS --
    0x111/0x113 data is [steps:uint32 big-endian][dir], move N steps then stop
    (blocking); 0x115 BMS toggles the 12V rail (persistent). Reworked control to match:
    - motorFrame encodes a real step count (default 255, -steps / TTOS_DASH_STEPS);
    the wire bytes are byte-identical to the original app ([00 00 00 FF dir]).
    - 12V is now a persistent commanded power state (not a 4s window); the indicator
    reflects it. A motion command powers the rail on if needed; STOP powers it off
    (true e-stop -- steppers already halt after each move).
    - UI: direction buttons are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
2026-07-31 firmware: BMS ADC ref is 3.3V (RP2040), not 5V -- fixes battery over-read
    The nodes are RP2040 (Feather RP2040 CAN, 3.3V), so ADC_REF_MV=5000 over-read the
    pack by 5000/3300 = 1.515x (16.1V shown for a ~10.7V pack). Set ADC_REF_MV=3300;
    updated README (RP2040 board, correct FQBN).
    [TinytrekBMS.ino]
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2026-08-02 ctf phase 0: close the bypasses that made the challenges irrelevant
    Three ways a contestant could skip the challenge chain entirely, plus the
    pre-event check that catches a car in an unsafe state.
    Remove socketcand. It bridged BOTH CAN buses to TCP 29536 with no
    authentication, so anyone on the network had raw drive-bus access and the
    gateway, C1 and C2 were all moot. Restricting it to the diagnostic bus would
    not have saved it either: socketcand is only a front-end to the Pi's own can0
    controller, so it adds no second node to ACK and a contestant without a
    physical tap cannot transmit or receive regardless. Diagnostic access is now
    the physical side tap only. The recipe stays in the layer,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
2026-08-02 docs: system overview and challenge-layering review/plan
    SYSTEM-OVERVIEW.md -- the baseline as built, written as a handoff for challenge
    design rather than a general README.
    CHALLENGE-PLAN.md -- review of the layering brief against the actual repo, with
    the phase plan. Records the decisions taken so far, including two corrections to
    the brief and one to my own earlier advice:
    - socketcand cannot serve as a contestant path at all (no second node to ACK),
    so it is dropped rather than restricted -- tap or nothing.
    - BMS stand-down uses the heartbeat's already-reserved flags byte as an ARM
    mask, not a "redeemed" flag: with arm semantics every failure mode leaves
    detection disarmed, so a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
2026-08-02 ctf phase 1: gateway policy, CTF service layer, UDS-lite diagnostic server
    Foundation the challenges hang off. No challenge content yet -- no routines, no
    snapshot, no flags.
    DIAG bus to CAN FD. can0 was classic 500k; it now runs 500k arbitration /
    1 Mbit data, which is what lets a routine return a flag inside one 64-byte
    response with no ISO-TP segmentation anywhere. Both .network files had comments
    describing the pre-2026-08-01 (inverted) bus roles; rewritten to the verified
    layout and to role names, with the FD hazard on the DRIVE bus spelled out.
    ttos-cangw applies the kernel gateway policy: DRIVE -> DIAG forwards the flag
    frames 0x7D1/0x7D2 only, nothing is forwarded inbound, classic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
2026-08-02 ctf phase 0 fix: socketcand was still shipping via can-utils-access
    Removing the standalone socketcand recipe from IMAGE_INSTALL did not actually
    get socketcand off the image. cangw is packaged in can-utils-ACCESS, not the main
    can-utils package, and that same subpackage ships socketcand -- along with
    bcmserver, canlogserver and cannelloni, which are the same class of thing:
    unauthenticated network bridges to a CAN bus.
    We need can-utils-access for cangw, so the image recipe now deletes those four
    binaries at rootfs assembly, and ttos-cangw depends on the correct package
    instead of one that does not contain the tool it needs.
    None of them ships a systemd unit, so nothing was listening on a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
2026-08-02 firmware: make motor CAN init survive a cold start, and show board faults
    A failed CAN init left a motor node deaf for the whole session, and looked
    identical to a disconnected bus from every vantage point we had.
    The MCP2515 needs its oscillator running before it answers over SPI -- 128
    oscillator cycles for the start-up timer plus crystal settling, which from cold
    is hundreds of microseconds to milliseconds. The vendored library's reset() waits
    10us. So begin()'s CANCTRL readback can lose that race at power-on and win it on
    a warm reset, which is exactly the "boots dead, works on the bench" pattern.
    When it lost, the sketch printed to a serial port nobody was attached to and
    carried on.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
    [TinytrekLMotor.ino, TinytrekRMotor.ino]
2026-08-02 dashboard: turn rpm 50 -> 100, out of the stepper resonance band
    At 200 full steps/rev with no microstepping, 50 rpm is 167 steps/s -- inside the
    ~100-200 pps mid-band resonance region. The rotor oscillates about each detent
    instead of settling, so turns ground audibly, lost torque, and dropped steps,
    running slower than the intended halving. Straight runs at 333 steps/s, above the
    band, which is why only turns were affected. Confirmed on the car: the noise is
    gone at 100.
    The comment records why, because "make turns gentler" is the obvious change that
    walks straight back into it, and warns that the textbook fix -- microstepping --
    would break Challenge 1's 102-step pivot and overrun STEPS_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
2026-08-02 DRIVE bus back to classic CAN 2.0; stop the self-test flushing the gateway
    can1 was configured FDMode=yes with a 1 Mbit data rate. Nothing on that bus can
    use it -- the motor nodes are MCP2515, which has no CAN FD support at all -- and
    it left the Pi able to transmit a frame that is a form error to those nodes,
    driving them error-passive and then bus-off, stopping propulsion. The hazard was
    documented in three places and guarded by the gateway's classic-only forwarding
    rather than simply removed. With FD off the controller cannot emit an FD frame at
    all, so the gateway rule is now redundant protection instead of the only defence.
    can0 (DIAG) stays FD: that is where 64-byte diagnostic respons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
2026-08-03 bench: in-loop test rig on arcana (role-pinned adapters, loopback-safe observer, 2s hot reload)
    Two PCAN-USB FD adapters pinned by udev to ROLE names (ttdrive/ttdiag) rather
    than can0/can1: the physical wiring here is the opposite of the bench brief's
    table, and renumbering would only move the trap. bench-up.sh re-verifies the
    mapping against the DUT's 0x100 heartbeat on every run.
    The brief's prescribed fix for the loopback trap does not work. CAN_RAW_LOOPBACK
    governs the TRANSMITTING socket, so clearing it on an observer is a no-op --
    measured both ways on the rig. It also passes the brief's own self-test, because
    a socket that receives nothing also fails to see the injected frame. Observ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
2026-08-03 Phase 2: C1 pivot routine, protected drive frames, and a shipping-blocker fix
    Pivot routine on RID 0x0201: 102 steps per wheel, opposite directions, ONE command
    per wheel, C1 code in the routineStatusRecord of the positive response. At 12 bytes
    that response only fits because the DIAG bus is CAN FD, which is the whole reason
    no segmentation layer exists on either side.
    protect.go implements CRC-8/SAE-J1850 keyed by the per-motor Data ID, AUTOSAR E2E
    Profile 1 style (Data ID prefixed, low byte first). Cross-checked against the
    standard vector (0x4B) and byte-for-byte against the bench Python implementation.
    Covers bytes 0..6 including the nonce, per CHALLENGE-PLAN I.3: covering only 0..5
    lea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
2026-08-03 flash prep: pivot tunables in the defaults, non-interactive build.sh, DUT sudo preflight
    build.sh passed docker -t unconditionally, so any non-interactive run died with
    'the input device is not a TTY' AND EXITED 0 -- a build that produced nothing but
    reported success. Same class of trap as the earlier cangw -L exit 36. Now -t only
    when stdout is a terminal.
    ttos-dashboard.default gains TTOS_PIVOT_STEPS/TTOS_PIVOT_RPM with the resonance vs
    tier-separation conflict written down at the point of use, since that value is also
    compiled into every BMS.
    The three DUT scripts now preflight sudo and say what to do when it fails: after
    real provisioning the factory password is gone and DUT_PASS has t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
2026-08-03 Phase 4: C3 authenticated telematics relay, solvable end to end
    Raw-CAN relay on the DRIVE bus behind a key derived from vehicle identity:
    SHA-256(vin:serial:fleet_salt)[:16]. Constant-time compare, malformed-vs-wrong
    distinction, per-IP rate limiting, monotonic sequence logging. No filesystem, no
    command execution, no config read -- a shell here would hand over the Data ID and
    collapse C2 and C3 in one step.
    Binds the AP address only. 0.0.0.0 would put a network path to the drive bus on
    the wired side too, which is the exact hole socketcand was removed for; the test
    suite asserts it is NOT reachable over Ethernet.
    DID 0xF1A1 advertises the endpoint -- one of two discovery paths, the other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
2026-08-03 Phase 5: unlock tiers, sessions, judging record, reset command
    Tier ladder with crypto/rand session tokens: HttpOnly SameSite=Lax cookie holding
    an opaque 32-byte token, server-side map, 10-minute SLIDING idle so a team
    grinding C2 for two hours is not repeatedly kicked back to locked.
    Two pieces of state kept deliberately separate, because conflating them is the
    bug this design is most likely to have:
    SESSION tier -- per browser, what this client may SEE
    CAR record -- per car, tiers redeemed since reset; drives the BMS arm mask and
    is the judging path
    Driving the arm mask from session tier would silently RE-ARM the detectors when a
    second tab opened or a session idl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
2026-08-03 bench: record Phase 4/5 findings and the full matrix status
    Matrix now G1-G6, D1-D10, C1-C4/C6-C8, P1-P8 and the relay suite. Outstanding are
    the two soaks: C5 (30 minutes of legitimate operation emitting zero flags) and D11
    (ENOBUFS tolerance with the DIAG bus down).
    Also notes that the suites must run one at a time -- they inject on both buses, so
    a parallel run fails D1 on another suite's traffic.
2026-08-03 journald: MaxRetentionSec deletes the entire boot log on a board with no RTC
    Self-inflicted, and it destroyed exactly what the persistent journal was added to
    preserve.
    This board has no RTC, so it boots with a stale clock and everything logged before
    timesyncd catches up carries that old timestamp. The moment the clock jumps
    forward, a time-based retention rule sees those entries as years old and vacuums
    them immediately. Measured on the clean flash: the first surviving entry in the
    whole journal was 'Initial clock synchronization', and every line before it --
    provisioning, CTF identity load, gateway policy, UDS and relay startup -- was gone.
    Verified by removing it and rebooting: boot 0'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
2026-08-03 tools: refuse /dev/tty.* on macOS, point at /dev/cu.*
    macOS exposes two nodes per serial device. Opening the call-in node (/dev/tty.*)
    blocks until carrier detect asserts, which on a USB CAN adapter may be never, so
    the tool hangs with no error and nothing to debug. /dev/cu.* is the call-out node
    and does not wait.
2026-08-03 fleet-wide firmware: three binaries instead of twenty-four
    Data IDs and unlock codes are now fleet-wide rather than per-car, so there is one
    left-motor, one right-motor and one BMS binary for all eight cars. Per-car identity
    stays Pi-side and provisioned -- hostname, WiFi, VIN, ECU serial, console password.
    The decisive argument is operational, not security. Per-car secrets meant a car
    dying mid-challenge -- flat pack, wedged Pi, damaged node -- cost that team the work
    they had done, because the Data ID and codes they recovered did not apply to a
    replacement. Uniform firmware makes any car a drop-in spare. Twenty-four unique
    builds also meant twenty-four chances to put the wrong board in th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
2026-08-03 provision nodes automatically on first boot; expand the challenge narrative
    Node provisioning now runs by itself on the first boot with a provisioning file
    present, gated by a marker in the systemd StateDirectory so it never repeats. The
    entire per-car setup is once again one file on the boot partition -- nobody shells
    into eight cars. ttos-provision-nodes survives only for the case where a node is
    replaced later.
    One-shot still matters for the reason it always did: the burst carries the Data IDs,
    and repeating it every boot would put the answer to Challenge 3 on the bus each time
    a car is power-cycled, which during an event is whenever a team asks for one.
    Verified on the DUT: first start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
2026-08-03 tools: PEAK PCAN-USB FD transport for macOS; ARCHITECTURE.md is the source of truth
    A PEAK adapter on macOS is a raw USB device driven by libPCBUSB through IOUSBKit --
    it creates no /dev/cu.* node at all, so --port had nothing to point at and neither
    existing transport could reach it. Not a wrong flag; a missing code path.
    Adds a pcan transport, hand-rolled ctypes against the PCANBasic C API rather than
    vendoring PCANBasic.py, so the tool stays ONE FILE you can copy to a laptop -- the
    property that matters for something carried to an event. --transport now defaults
    per platform (pcan on macOS, socketcan on Linux), so the common case needs no flags.
    FD bitrate defaults to the timings the be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
2026-08-03 tools: probe transmits and reads back bus state; fix the bitfield check on the TX path
    PCANBasic returns a status BITFIELD. Both send and recv compared it for equality,
    so a benign bus-condition bit -- which is exactly what a lone adapter on an
    unterminated wire reports constantly -- looked fatal. recv bailed out of its poll
    loop and send raised. Both now mask.
    probe previously proved nothing about the hard part: it only listened, and the
    diagnostic bus being silent is the expected result, so it went green on a path that
    had never received a frame or completed a transmission.
    It now sends a TesterPresent and reads the controller's own bus state back. A CAN
    frame is only complete when anoth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
2026-08-03 tools: burst test, so a clean bus is a positive result rather than an absence
    A single clean transmit was ambiguous in exactly the way that matters: 'sent and
    acknowledged' and 'never actually left the adapter' both present as a healthy bus,
    because no transmission means no errors. That let probe report the wiring as fine
    without having proven the pcan transmit path does anything at all.
    Fifty unacknowledged frames push a controller's transmit error counter past 256 and
    into BUS-OFF. So a bus that is still clean after a burst is evidence that the frames
    went out and something acknowledged them, rather than evidence of nothing happening.
    Only runs when nothing replied -- there is no reason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
2026-08-03 firmware: self-contained sketch folders, so the Arduino IDE just works
    Each sketch now carries the library sources it needs -- the CAN driver, the NeoPixel
    driver, and on the SAMD motors the flash-as-EEPROM code. Open the .ino, pick the
    board, upload. No libraries to install, no symlinks, no vendored tree to point a
    compiler at, no FQBN to look up.
    The vendored libraries/ directory and link-libraries.sh are gone, and build.sh is
    demoted to an optional batch builder that nothing depends on. Vendoring plus
    --libraries was a workflow of my own invention and it made the standard path -- open
    it in the IDE -- the broken one, which is backwards for something 24 boards have to
    go through.
    Include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
    [ESP32SJA1000.h]
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2026-08-04 fix the review findings: dead rail on C1/C2, e-stop ordering, code leak, silent resets
    A six-lens review with adversarial verification found 33 surviving issues. These
    are the ones that would have hurt during an event, plus the tests that let them
    through. Everything below is verified on the bench or the DUT unless marked.
    BMS FIRMWARE (requires a reflash; all three in TinytrekBMS.ino)
    D4 haveC2/haveC3 were set by the chunk-1 branch alone, so "I saw the last
    chunk" meant "I have the whole code". A node that missed chunk 0 -- the
    case the 6-second repeat burst exists to cover -- latched six zero bytes,
    stored it, and then refused all further config because cfgReady() had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
    [TinytrekBMS.ino, vehicle-emulator.py]
2026-08-04 BMS reports its stored config, so a latched-bad node is visible before an event
    The D4 fix stops new boards from latching a malformed code; it does nothing for a
    board that already did. cfgLoad() sees the magic byte, restores the wreckage, and
    cfgReady() goes true -- so the node refuses all further code config, on a store
    that lives in flash rather than on the Pi's SD card and therefore survives both a
    card wipe and (depending on the upload path) a sketch reflash. Nothing reported
    that state, so the first symptom would have been a garbage flag mid-event.
    Prints a FINGERPRINT, not the codes: this is a USB port on a board inside a car
    contestants have physical access to. Enough to compare two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
    [TinytrekBMS.ino]
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2026-08-04 drop CHALLENGE-PLAN.md and judge-packet.md; unwire both from the generators
    Both were stale in ways that would have misled someone during an event.
    CHALLENGE-PLAN predated ARCHITECTURE.md and disagreed with it. judge-packet listed
    per-car unlock codes after the fleet went uniform, and named an exact Data ID when
    a correct Challenge 3 solve recovers a 256-member equivalence class and cannot
    identify the true value -- measured today, and now written into WALKTHROUGH.md.
    Deleting the file was not enough: render-fleet.py and gen-fleet.py BOTH generated
    judge-packet.md, so the next render would have restored it. Removed from both.
    Verified a render now emits 8 car configs and no packet.
    Nothing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
    [vehicle-emulator.py]
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
